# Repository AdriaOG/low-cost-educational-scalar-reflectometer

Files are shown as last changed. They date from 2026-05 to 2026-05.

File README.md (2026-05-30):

# Low-Cost Educational Scalar Reflectometer for Microwave Teaching

**Low-cost PCB-based scalar reflectometer (50 MHz–1 GHz) for hands-on teaching of reflection coefficient measurement, antenna impedance matching and RF hardware in microwave engineering courses.**

This repository contains all the materials required to reproduce the educational platform presented in the paper:

> A. Ortiz, J. Navarro, J.L. Pijoan, and J. Anguera, “A Low-Cost Educational Reflectometer for Microwave Teaching”,2026.

## Overview
The platform implements a complete **scalar reflectometer** on a single two-layer PCB using off-the-shelf components. It exposes the full measurement chain (directional coupler, passive envelope detectors, configurable analog conditioning, and embedded microcontroller) so that students can understand how |S₁₁| is obtained from RF signals in a transparent and modular way.

Designed specifically for undergraduate and graduate courses in microwave engineering, the system supports the complete 10-stage laboratory sequence described in the paper.

## Key Features
- Broadband directional coupler (directivity 8–15 dB)
- Passive Schottky envelope detectors with three configurable analog modes: passive, unity-gain buffer, and fixed-gain amplification
- Low-cost microcontroller with real-time |S₁₁| computation and serial streaming
- Full pedagogical transparency of the entire signal path
- 10-stage progressive laboratory sequence (theoretical foundations → PCB design → fabrication → automated measurements → open-ended projects)
- Multidisciplinary integration: microwave theory, analog electronics, embedded systems, and antennas
- Reproducible with standard two-layer PCB fabrication and widely available components

## Repository Contents

The repository is organized as follows:

```bash
low-cost-educational-scalar-reflectometer/
├── bom/               # Bill of Materials (Excel)
├── firmware/          # Microcontroller source code (C)
├── gerbers/           # Fabrication files (Gerber X2)
├── hardware/          # Altium schematic + PCB layout (v1.0)
├── software/          # Python/MATLAB scripts for automated sweeps and post-processing
└── README.md
```
## Repository Contents
- Fabricate the PCB using the provided Gerber files (standard 2-layer process).
- Assemble the board following the BOM.
- Flash the firmware and connect to a PC via USB.
- Follow the 10-stage laboratory sequence (adaptable to different course lengths).

## Citation
If you use this platform or any of its materials in your teaching or research, please cite the original paper:
```bibtex
bibtex@article{ortiz2026reflectometer,
  author  = {A. Ortiz and J. Navarro and J.L. Pijoan and J. Anguera},
  title   = {A Low-Cost Educational Reflectometer for Microwave Teaching},
  journal = {IEEE Transactions on Education},
  year    = {2026},
  doi     = {10.1109/TE.2026.xxxxxxx}
}

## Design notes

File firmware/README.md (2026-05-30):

# Firmware – PIC18F4321  
**Scalar Reflectometer Educational Platform**

This firmware runs on the **PIC18F4321** microcontroller of the low-cost educational scalar reflectometer. It performs real-time acquisition of the forward and reverse envelope detector voltages, computes the magnitude of the reflection coefficient |S₁₁|, streams the results via TTL serial communication to a host PC, and provides a GPIO interface for future extensions (tunable matching networks, RF switches, etc.).

Compatible with the platform described in the paper:  
**“A Low-Cost Educational Reflectometer for Microwave Teaching”**  

## Pin Configuration (PIC18F4321)

| Pin | Function | Direction | Usage in this firmware | Educational purpose |
|---|---|---|---|---|
| **RA0** | AN0 | Input | ADC Channel – Forward detector voltage | Proportional to incident RF power |
| **RA1** | AN1 | Input | ADC Channel – Reverse detector voltage | Proportional to reflected RF power |
| **RA2–RA5**| AN2–AN5 | Input | Reserved / available for additional sensors | Future extensions |
| **RC6** | TX (EUSART) | Output | TTL serial transmission (115200 baud) | Data streaming to PC (|S₁₁|, voltages, status) |
| **RC7** | RX (EUSART) | Input | TTL serial reception | Commands from PC |
| **RD0** | SCLK (GPIO) | Output | GPIO clock line | Control of external devices |
| **RD1** | SDATA (GPIO) | Output | GPIO data line | Control of external devices |
| **RD2–RD7**| GPIO | — | Free general-purpose I/O pins | LEDs, buttons, displays, RF switches, etc. |
| **RB0–RB7**| GPIO / Interrupt | — | Not used in this version | Available for advanced projects |
| **VDD/VSS**| Power supply | — | 5 V (regulated from USB) | Full board power |

> Note from source code: `TRISD = 0xFC;` configures RD0 and RD1 as outputs for the MIPI interface, leaving the rest of PORTD available.

## Code Structure

- `main.c`          → Main loop (`while(1) { MotorADC(); }`)
- `adc.h / adc.c`   → ADC initialization and dual-channel reading
- `sio.h / nova_sio.h` → EUSART serial communication (TX/RX TTL)
- `PacketLogic.h`   → Packet formatting sent to the host PC
- `TTimer.h`        → Timer and high-priority interrupt management
- `MIPI.c`          → `initMIPI()` and `SendMIPIconfig()` functions

## Main Functionality

- Simultaneous sampling of both envelope detectors using the internal ADC
- Basic offset correction and single-point calibration
- Real-time computation of |S₁₁| magnitude
- Continuous streaming of results over the serial port (easy visualization with any terminal or Python/MATLAB scripts)
- GPIO control interface ready for extensions (Stage 10 of the laboratory sequence)

## How to Compile and Flash (for students)

1. Open the project in MPLAB X IDE with the XC8 compiler.
2. Build the project.
3. Program the PIC18F4321 using PICkit 4, SNAP, or the on-board USB bootloader.
4. Connect the reflectometer USB port to a PC — it appears as a standard COM port.

## Educational Notes for Students (aligned with Sections V and VI of the paper)

- Students can easily modify `MotorADC()` to add averaging, multi-point calibration, VSWR calculation, or return-loss conversion.
- Changing baud rate or adding new commands is straightforward thanks to the modular `nova_sio` library.

## License
MIT License – Feel free to modify and redistribute while preserving the original authorship.

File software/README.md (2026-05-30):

# Software – Automation and Visualization Scripts  
**Scalar Reflectometer Educational Platform**

This folder contains the two scripts required to perform automated measurements and generate the comparative plots shown in Section IV of the paper.

- `rigol_power_frequency_sweep.py` → Controls the RIGOL DSG821 RF signal generator and the reflectometer microcontroller simultaneously.
- `plot_reflectometer_vs_VNA.m` → MATLAB script that compares the reflectometer measurements against the reference VNA data (AntennaVNA.s1p).

These scripts are fully commented and designed to be easily adapted by students (Stage 8 and Stage 9 of the laboratory sequence).

## 1. Python Script: Automated Power & Frequency Sweep (`rigol_power_frequency_sweep.py`)

**Purpose**  
Performs a 2D sweep (frequency × input power) using the RIGOL DSG821 generator and reads the ADC values (RA0 = forward, RA1 = reverse) from the PIC18F4321 via serial port.  
Saves one CSV file per power level: `measures_0dBm.csv`, `measures_5dBm.csv`, …  

**Key Configurable Variables** (edit at the top of the script)

RIGOL_IP = "192.168.1.100"          # IP of your RIGOL generator
SERIAL_PORT = "COM3"                # Serial port of the reflectometer
START_FREQ_HZ = 50e6                # Start frequency
STOP_FREQ_HZ  = 2.1e9               # Stop frequency
STEP_HZ       = 10e6                # Frequency step → change here
POWERS_DBM    = list(range(0, 21, 5))   # Example: 0, 5, 10, 15, 20 dBm
#POWERS_DBM = list(range(-30, 21, 2))  # Uncomment for finer power sweep
Special Function
transform_csv_to_excel(input_csv, output_xlsx)
→ Converts each measures_XXdBm.csv into Excel format required by the MATLAB script, applies unit conversion (Hz → MHz and raw ADC → volts), and renames columns.
Usage
Bashpython rigol_power_frequency_sweep.py
After finishing, run:
Pythontransform_csv_to_excel("measures_0dBm.csv", "measures_0dBm.xlsx")
# repeat for each power level or automate in a loop
Adaptation
The script uses standard SCPI commands (FREQ, POW, OUTP). It can be easily extended to any other generator of the RIGOL DSG family or any instrument supporting pyvisa/SCPI by changing only the connection string and command syntax.
2. MATLAB Script: Comparison with VNA Reference (plot_reflectometer_vs_VNA.m)
Purpose
Loads the reference S-parameter file from a professional VNA and overlays the reflectometer measurements (for different input power levels) to evaluate dynamic range, sensitivity and agreement with the reference.
Key Configurable Variables
matlabs1pFile = 'AntennaVNA.s1p';           % Reference file from VNA (DUT = antenna)

values_dBm = 0:5:20;                  % Powers to plot → change here (must match Excel files)
% Example: values_dBm = [0 5 10 15 20];
Required files in the same folder

AntennaVNA.s1p          → Touchstone file exported from the VNA (reference |S₁₁|)
measures_0dBm.xlsx, measures_5dBm.xlsx, … (generated by the Python transform function)

Features

Automatic plotting of VNA reference + all selected power levels
Interactive legend (click on a curve to hide/show it)
Pre-configured axes and limits matching the figures in the paper

Usage

Place all Excel files and the .s1p file in the same folder as the script.
Open and run plot_reflectometer_vs_VNA.m in MATLAB.
Modify values_dBm and re-run to explore different power configurations.

Workflow Summary (for students – Stage 8 & 9)

Configure and run rigol_power_frequency_sweep.py → generates CSV files
Convert CSVs to Excel using transform_csv_to_excel(...)
Run plot_reflectometer_vs_VNA.m → obtain publication-quality comparison plots

All scripts are intentionally kept modular so students can experiment with different frequency steps, power ranges, calibration improvements, or even replace the RIGOL generator with another instrument.

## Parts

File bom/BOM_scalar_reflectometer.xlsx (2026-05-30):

Comment | Description | Designator | Footprint | LibRef | Quantity | Mouser Description | Mouser Part Number | Manufacturer | Manufacturer Part Number | Manufacturer URL
GCM1555C1H102FA16D | Capacitor | C1, C3 | GCM155 | GCM1555C1H102FA16D | 2 |  | 81-GCM1555C1H102FA6D
GRM188R71H104KA93D | Chip Capacitor, 0.1 uF, +/- 10%, 50 V, -55 to 125 degC, 0603 (1608 Metric), RoHS, Tape and Reel | C2, C4, C5, C6, C7, C8 | CAPC1608X90X35ML10T15 | CMP-2100-03643-1 | 6 |  |  | Murata |  | http://www.murata.com/
BAT1502ELE6327XTMA1 | DIODE SCHOT 4V 110MA TSLP-2-19 | D1, D2 | FP-PG-TSLP-2-MFG | CMP-32890-000023-1 | 2
1N4148 | DIODE GEN PURP 100V 200MA DO35 | D3 | FP-017AG-MFG | CMP-07163-000046-1 | 1
HHM22137A2 | Circulator or Directional Coupler | HY1 | HHM22137A2 | HHM22137A2 | 1 |  | 810-HHM22137A2
TLV1117-18CDCYR | Integrated Circuit | IC1 | SOT230P700X180-4N | TLV1117-18CDCYR | 1 |  | 595-TLV1117-18CDCYR
LTC2066IS5#TRPBF | Integrated Circuit | IC2, IC3 | LTC2066IS5TRPBF | LTC2066IS5#TRPBF | 2 |  | 584-LTC2066IS5TRPBF
90120-0123 | Connector | J1, J4 | HDRV3W90P0X254_1X3_762X249X560P | 90120-0123 | 2 |  | 538-90120-0123
90120-0125 | Connector | J2 | HDRV5W90P0X254_1X5_1270X250X965P | 90120-0125 | 1 |  | 538-90120-0125
10-89-7080 | Connector | J3 | HDRV8W87P254_2X4_1029X508X864P | 10-89-7080 | 1 |  | 538-10-89-7080
90120-0121 | Connector | J5, J6 | HDRV1W65P0X254_1X1_232X249X560P | 90120-0121 | 2 |  | 538-90120-0121
901-143-6RFX | Coaxial connector, 50 Ohm, -65 to 165 degC, 5-Pin THD, RoHS, Bulk | J7, J11 | AMPH-901-143-6RFX_V | CMP-2000-05705-1 | 2 |  |  | Amphenol |  | http://www.amphenol.com/
MM8130-2600RA2 | Connector | J9, J12 | MM81302600RA2 | MM8130-2600RA2 | 2 |  | 81-MM8130-2600RA2
217175-0001 | CONN RCP USB2.0 C 6+18P SMD RA | J10 | FP-217175-0001-MFG | CMP-04767-000026-1 | 1
FC0402E50R0FTBST0 | FC0402E50R0FTBST0 SMD Chip Resistor, 50 Ohm, ± 1%, 50 mW, 0402 [1005 Metric], Thin Film, High Frequency | R1, R3 | FP-FC0402-MFG | CMP-00030-23258606-1 | 2
AC0603FR-071ML | RES 1MΩ 1.00% 0.1W 0603 | R2, R4, R10, R11 | FP-AC0603-IPC_C | CMP-2000-04829-2 | 4
AC0603FR-071KL | RES 1kΩ 1.00% 0.1W 0603 | R5, R6 | FP-AC0603-IPC_B | CMP-2000-04828-3 | 2
CRCW06035K11FKEA | RES Thick Film, 5.11kΩ, 1%, 0.1W, 100ppm/°C, 0603 | R7, R9 | FP-CRCW0603-e3-IPC_B | CMP-2000-03482-2 | 2
RP73PF1J2K21BTDF | RES SMD 2.21K OHM 0.1% 1/6W 0603 | R8 | FP-RP73P-1J-MFG | CMP-03211-008097-1 | 1 |  |  | TE Connectivity | RP73PF1J2K21BTDF
RK73Z1JTTD | RES 0 OHM JUMPER 0603 | R12, R13, R16, R17, R18, R19 | FP-RK73Z1J-MFG | CMP-2000-01769-2 | 6
RC0603FR-0710KL | RES 10K OHM 1% 1/10W 0603 | R14, R15 | FP-RC0603-0_55-IPC_C | CMP-2100-03664-2 | 2
EG1218 | Slide Switch, 500 V, -20 to 70 degC, 3-Pin THD, RoHS | SW1 | ESWI-EG1218_V | CMP-1696-00002-1 | 1
4-1437565-1 | SWITCH TACTILE SPST-NO 0.05A 24V | SW2 | FP-4-1437565-1-MFG | CMP-03407-000003-1 | 1 | Switch Tactile OFF (ON) SPST Round Button Gull Wing 0.05A 12VDC 1.57N SMD Loose Piece |  | TE Connectivity | 4-1437565-1
TCA9406DCTR | IC TRNSLTR BIDIRECTIONAL SM8 | U1 | FP-DCT0008A-MFG | CMP-0314-00292-3 | 1
PIC18F4321-I/P | Enhanced Flash Microcontroller with 10-Bit A/D and nanoWatt Technology, 8K Flash, 40-Pin PDIP, Industrial Temperature Range | U2 | PDIP600-P40 | CMP-0116-00016-1 | 1

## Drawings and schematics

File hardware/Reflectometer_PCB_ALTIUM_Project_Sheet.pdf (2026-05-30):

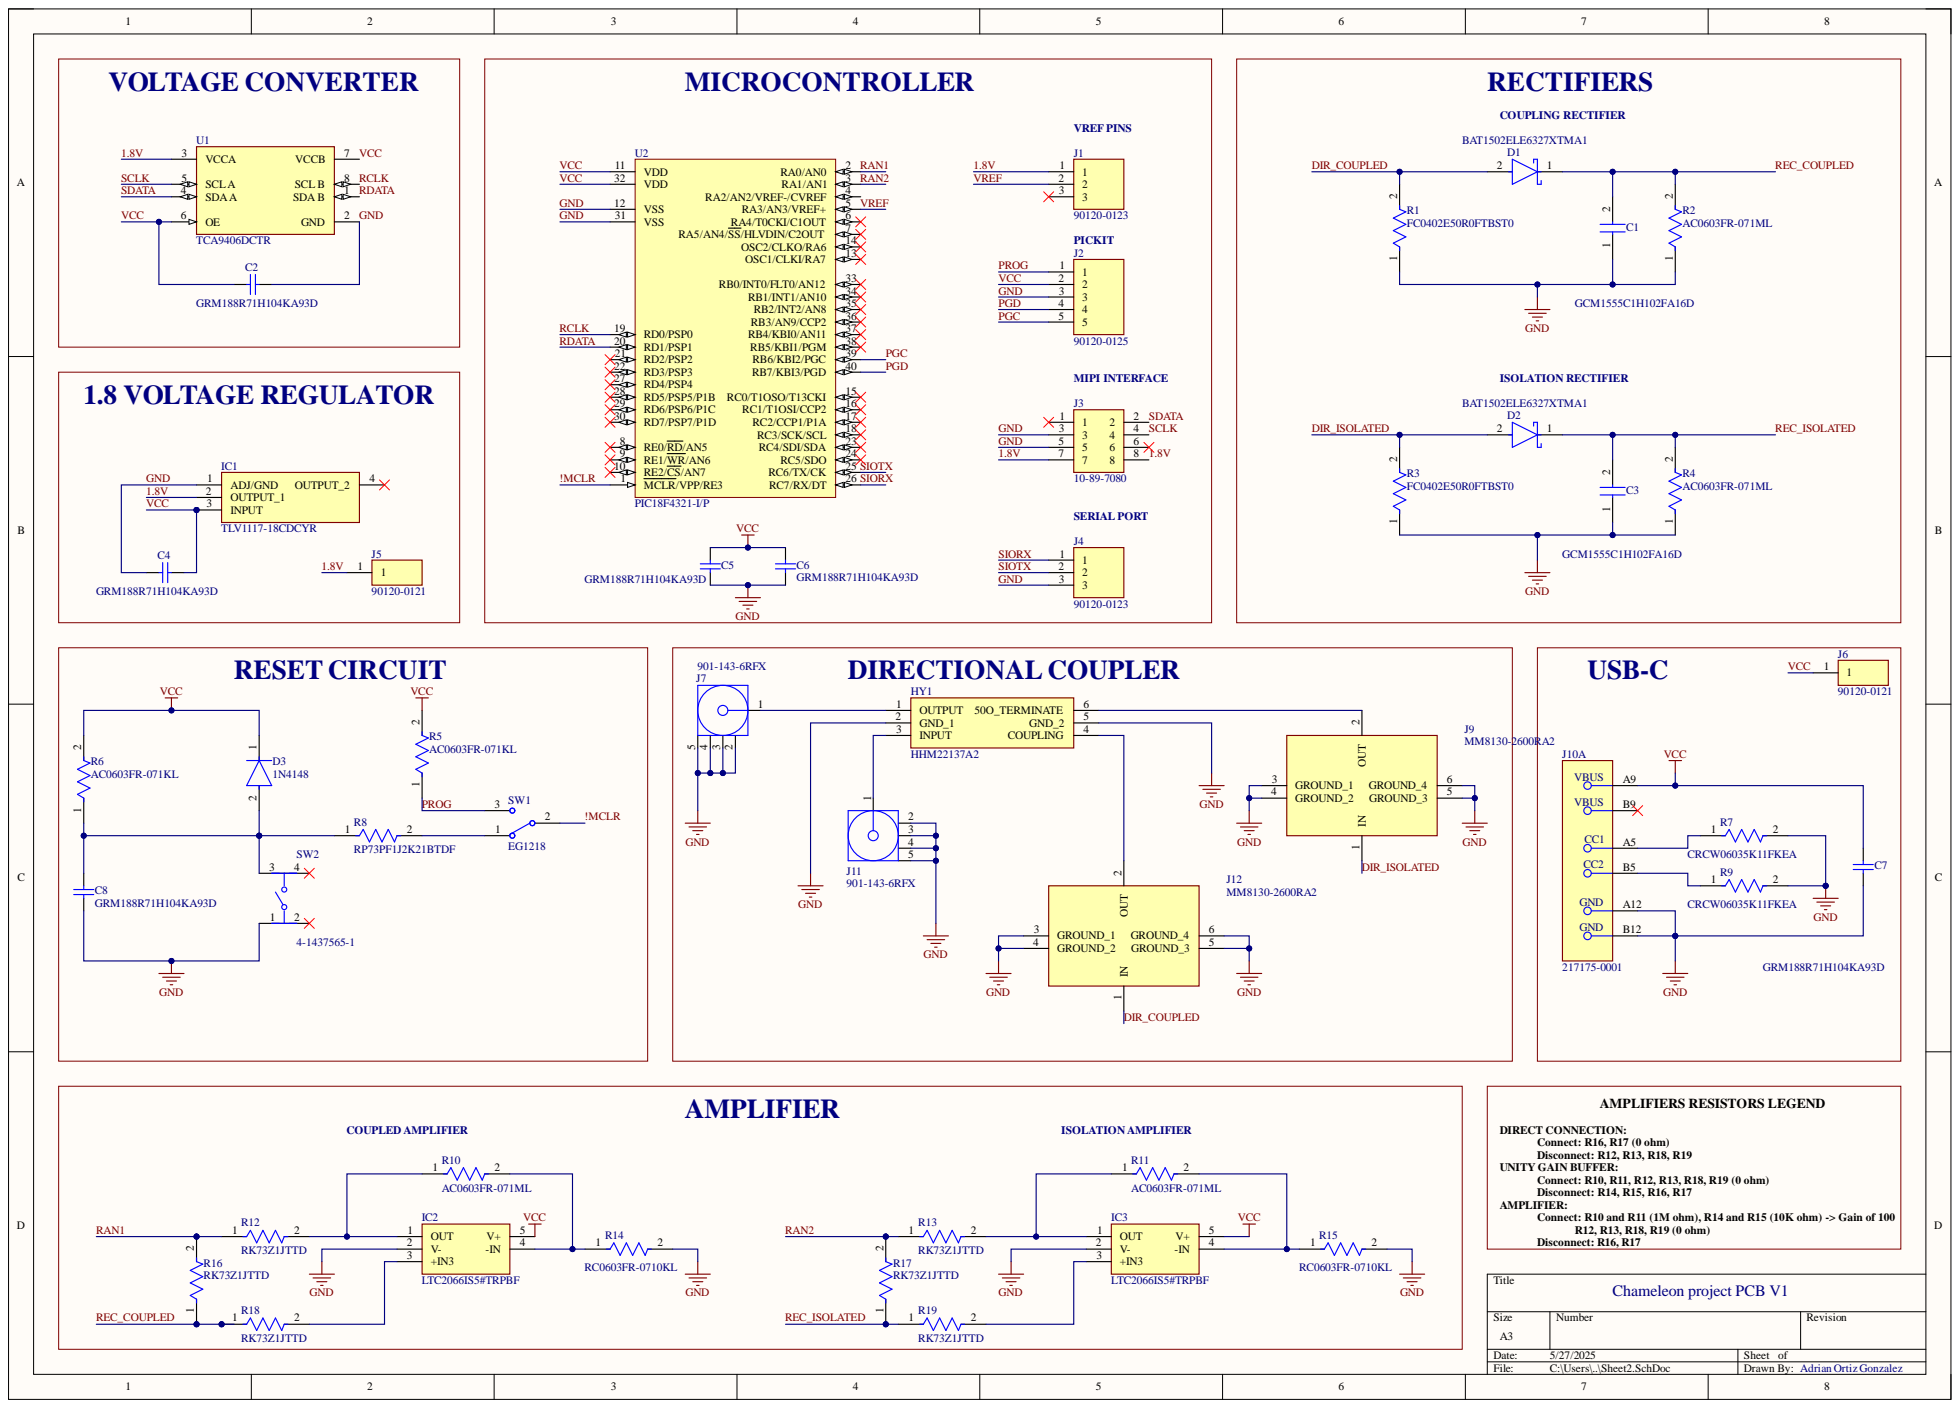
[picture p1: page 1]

Connect: R10 and R11 (1M ohm), R14 and R15 (10K ohm) -> Gain of 100

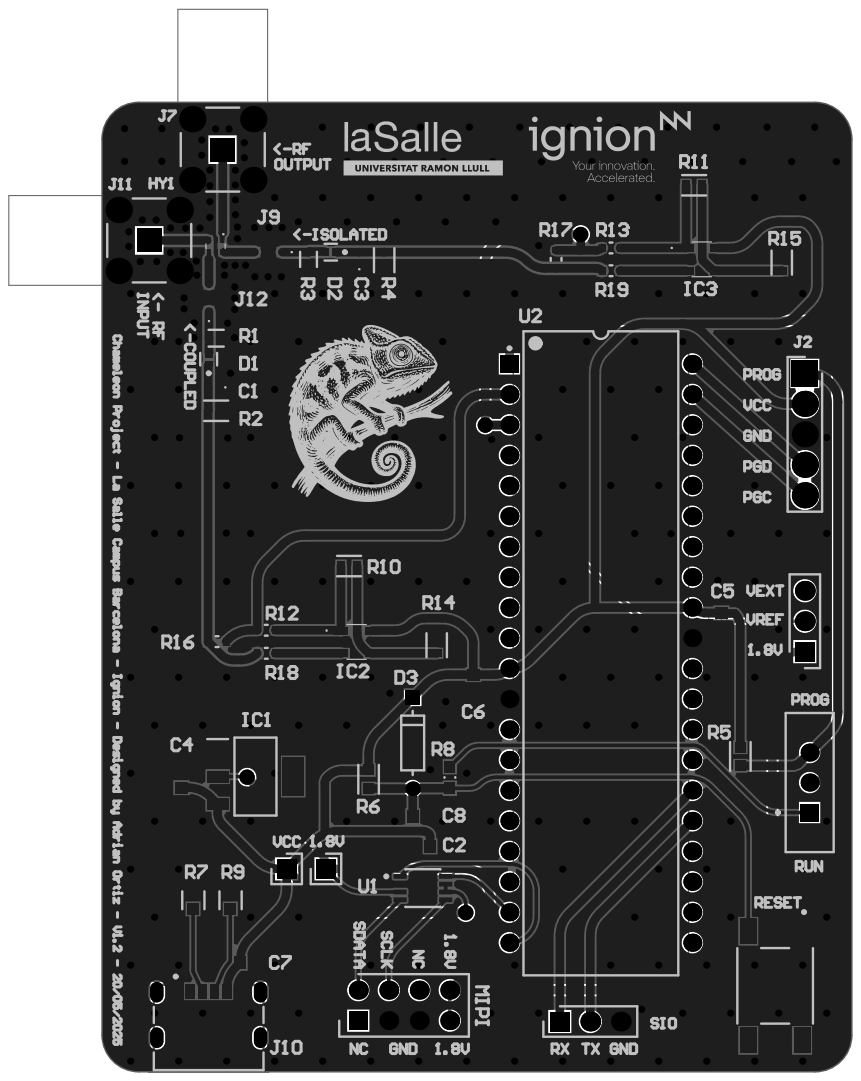
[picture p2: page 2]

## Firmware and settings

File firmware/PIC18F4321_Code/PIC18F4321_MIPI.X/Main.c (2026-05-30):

#include <xc.h>
#include "TTimer.h"
#include "PacketLogic.h"
#include "sio.h"
#include "adc.h"

#pragma config OSC = INTIO2
#pragma config PBADEN = DIG
#pragma config WDT = OFF
#pragma config LVP = OFF

void HighInterruptRSI(void);
void main(void);

unsigned char newConfiguration;
unsigned char oldConfiguration;
unsigned char oldAdc;

const unsigned char lookUpTable[30] = { 
    0x00, 0x01, 0x02, 0x03, 0x04, 0x05, 0x06, 0x07, 0x08, 0x09, 
    0x0A, 0x0B, 0x0C, 0x0D, 0x0E, 0xF0, 0xF1, 0xE2, 0xE3, 0xB4, 
    0xB1, 0x96, 0x97, 0x78, 0x71, 0x5A, 0x53, 0x3C, 0x35, 0x1E 
};

void __interrupt() RSI_High(void){
	_TiRSITimer();
}




void newConfigEusart(unsigned char receivedData) {
    while (!TXSTAbits.TRMT);
    TXREG = receivedData;
    switch (receivedData) {
        case '0':
            newConfiguration = 0x00;
            break;
        case '1':
            newConfiguration = 0x01;
            break;
        case '2':
            newConfiguration = 0x02;
            break;
        case '3':
            newConfiguration = 0x03;
            break;
        case '4':
            newConfiguration = 0x04;
            break;
        case '5':
            newConfiguration = 0x05;
            break;
        case '6':
            newConfiguration = 0x06;
            break;
        case '7':
            newConfiguration = 0x07;
            break;
        case '8':
            newConfiguration = 0x08;
            break;
        case 'A':
            newConfiguration = 0x05;
            break;
        case 'B':
            newConfiguration = 0x0B;
            break;
        case 'C':
            newConfiguration = 0x0E;
            break;
        case 'D':
            newConfiguration = 0x08;
            break;
    }
}

void newConfigADC(unsigned char receivedData) {
    if ((receivedData > oldAdc && (receivedData - oldAdc > 10)) || 
    (receivedData < oldAdc && (oldAdc - receivedData > 10))) {
        oldAdc = receivedData;
        if (receivedData < 32) {
            newConfiguration = 0x00;
        } else if (receivedData < 64) {
            newConfiguration = 0x01;
        } else if (receivedData < 96) {
            newConfiguration = 0x02;
        } else if (receivedData < 128) {
            newConfiguration = 0x03;
        } else if (receivedData < 160) {
            newConfiguration = 0x04;
        } else if (receivedData < 192) {
            newConfiguration = 0x05;
        } else if (receivedData < 224) {
            newConfiguration = 0x06;
        } else {
            newConfiguration = 0x07;
        }
    }
}

void main(void){
    ADCON1 = 0xFF;
    TRISA = 0xFF;
    TRISD = 0xFF;
    OSCCONbits.IRCF = 7;  //Internal oscillator @ 8MHz
    OSCTUNEbits.PLLEN=1;  //Fosc *=4; Final frequency 32 MHz
    TiInitTimer();
    initEUSART();
    tiStart();
    initADC();
    
    SIPuts("\n\rWelcome to Chamaleon! \n\r\0");
    
    
    
    unsigned char valor = 0;
    
    while (1){
        MotorADC();
        
        /*
         * if (getInternalCounter() > 33333){
            LATA = valor;
            valor = 255-valor;
            resetTimerCounter();
        }*/
    }
}

void main_old(void){
    ADCON1 = 0x0D;
    TRISA = 0x01;
    TRISB = 0xFF;
    TRISC = 0x00;
    TRISD = 0x00;
    INTCON2 = 0X00;
    LATDbits.LATD0 = 0;
    LATDbits.LATD1 = 0;
    LATAbits.LATA3 = 0;
    LATAbits.LATA4 = 0;
    newConfiguration = 0x0;
    oldConfiguration = 0x0;
    oldAdc = 0;
    unsigned int data = 0;
    unsigned char receivedData;
    
    // Initialize EUSART, ADC and TIMER
    initEUSART();
    initADC();
    TiInitTimer();
 
    //Initialization
    setData(0x0);
    setAddress(0x5C);
    SDATA();
    while (data < 10000) {
            data++;
    }
    data = 0;
    while(1){
         // Check if a byte is received
        if (PIR1bits.RCIF) { // RCIF is the EUSART Receive Interrupt Flag
            receivedData = RCREG; // Read the received byte
            newConfigEusart(receivedData);
        } /*else {
            // Perform ADC Conversion
            receivedData = readADC();
            newConfigADC(receivedData);
        }*/
        /*SDATA();
        while (data < 10000) {
            data++;
        }
        data = 0;*/
        
        if (newConfiguration != oldConfiguration) {
            oldConfiguration = newConfiguration;
            setAddress(0x40);
            setData(newConfiguration);
            resetHasBeenTimer();
            SDATA();
            setAddress(0x5C);
            setData(0x07);
            SDATA();
           /* while (data < 65000) {
                data++;
            }
            data = 0;*/
        }
    }		
}

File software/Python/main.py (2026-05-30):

import pyvisa
import serial
import time
import csv
import re
import pandas as pd

#ADJUST THE CONFIGURATION ACCORDING TO YOUR NEEDS
RIGOL_IP = "192.168.1.100"
VISA_BACKEND = "@py"

SERIAL_PORT = "COM3"
SERIAL_BAUDRATE = 9600

START_FREQ_HZ = 50e6
STOP_FREQ_HZ = 2.1e9
STEP_HZ = 10e6

#POWERS_DBM = list(range(0, 21, 2))   # 0, 2, 4, ..., 20 dBm
POWERS_DBM = list(range(0, 21, 5))   # -30,-28,-60 ... 0, 2, 4, ..., 20 dBm
#POWERS_DBM = list(range(0, 21, 10))   # -30,-28,-60 ... 0, 2, 4, ..., 20 dBm

def transform_csv_to_excel(input_csv, output_xlsx):
    # 1. Read CSV
    df = pd.read_csv(input_csv)

    # 2. Convert frequency from Hz to MHz
    df["freq_Hz"] = df["freq_Hz"].astype(float) / 1_000_000

    # 3. Multiply RA0 and RA1 by the factor (5/1024)
    factor = 5 / 1024
    df["RA0"] = df["RA0"].astype(float) * factor
    df["RA1"] = df["RA1"].astype(float) * factor

    # 4. rename Columns
    df.rename(columns={
        "freq_Hz": "f",
        "RA0": "m1p_coupled",
        "RA1": "m1p_isolated"
    }, inplace=True)

    # 5. Save as Excel
    df.to_excel(output_xlsx, index=False)
    print(f"File generated correctly: {output_xlsx}")





def read_current_values(ser):
    """
    The PIC sends several messages. We only want the following block:

        Current values:
        -> RA0: XXXX <-
        -> RA1: YYYY <-

    Strategy:
      - Read line by line until finding: "Current values:"
      - Read the next two lines
      - Extract XXXX and YYYY
    """

    while True:
        linea = ser.readline().decode(errors="ignore").strip()

        if "->" in linea:
            l_ra0 = ser.readline().decode(errors="ignore").strip()
            l_ra1 = ser.readline().decode(errors="ignore").strip()

            m0 = re.search(r"RA0:\s*(\d+)", l_ra0)
            m1 = re.search(r"RA1:\s*(\d+)", l_ra1)

            if not m0 or not m1:
                print("[WARNING] Could not parse RA0/RA1:")
                print(repr(l_ra0))
                print(repr(l_ra1))
                return None

            ra0 = int(m0.group(1))
            ra1 = int(m1.group(1))

            return ra0, ra1
        # If it doesn't match, we continue reading (we ignore short messages)
    # END while


def power_sweep(gen, ser, power_dbm):
    """
    Performs a complete frequency sweep for a power level, returning a list of tuples (freq, RA0, RA1).
    """

    results = []

    print(f"\n========== POWER: {power_dbm} dBm ==========")
    gen.write(f"POW {power_dbm}dBm")
    time.sleep(0.2)
    """
    Time changed. Original-> 0.1
    """

    print("Confirmed on generator:", gen.query("POW?").strip())

    freq = START_FREQ_HZ
    while freq <= STOP_FREQ_HZ:

        # 1) Configuring frequency of the generator
        gen.write(f"FREQ {freq}Hz")

        # 2) Send trigger to PIC
        ser.reset_input_buffer()
        ser.write(b"R")
        ser.flush()

        # 3) read complete block from the PIC
        medida = read_current_values(ser)

        if medida is None:
            print(f"[WARNING] Invalid measure at {freq/1e6:.1f} MHz")
            freq += STEP_HZ
            continue

        ra0, ra1 = medida
        results.append((freq, ra0, ra1))
        print(f"OK @ {freq/1e6:.1f} MHz -> RA0={ra0}, RA1={ra1}")

        # 4) we wait for the PIC to process its 10 samples
        time.sleep(0.2)

        # Next frequency
        freq += STEP_HZ

    return results


def main():
    # ------------------------
    # connection to the RF generator
    # ------------------------
    rm = pyvisa.ResourceManager(VISA_BACKEND)
    gen = rm.open_resource(
        f"TCPIP::{RIGOL_IP}::INSTR",
        timeout=5000,
        write_termination='\n',
        read_termination='\n'
    )

    print("IDN generator:", gen.query("*IDN?").strip())

    # ------------------------
    # Serial connection to the micro
    # ------------------------
    ser = serial.Serial(
        port=SERIAL_PORT,
        baudrate=SERIAL_BAUDRATE,
        timeout=None
    )

    print(f"Serial port open: {SERIAL_PORT} @ {SERIAL_BAUDRATE} bps")

    # ------------------------
    # Sweeping for every power
    # ------------------------
    try:
        gen.write("OUTP ON")

        for power in POWERS_DBM:

            results = power_sweep(gen, ser, power)

            # Guardar CSV correspondiente
            filename = f"measures_{power}dBm.csv"

            with open(filename, "w", newline="") as f:
                wr = csv.writer(f)
                wr.writerow(["freq_Hz", "RA0", "RA1"])
                wr.writerows(results)

            print(f">>> Saved: {filename}")
            print(f"    Total samples: {len(results)}")

    finally:
        try:
            gen.write("OUTP OFF")
        except:
            pass

        ser.close()
        gen.close()
        rm.close()
print("\n>>> PROCESS COMPLETED FOR ALL POWER LEVELS <<<")


if __name__ == "__main__":
    main()
